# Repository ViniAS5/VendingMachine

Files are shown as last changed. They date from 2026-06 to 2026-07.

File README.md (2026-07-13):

# Máquina de Vendas - Integração FPGA e ESP32 (CYD)

Projeto de uma máquina de vendas automatizada para 3 tipos de refrigerantes em lata. O sistema demonstra a integração entre hardware dedicado e Internet das Coisas (IoT), utilizando uma FPGA para controle de precisão e um ESP32 como interface de usuário e servidor web local.

Projeto final desenvolvido para a disciplina de **Eletrônica Digital 2** (2026.1) do curso de **Engenharia Eletrônica** do **IFSC - Câmpus Florianópolis**.

## Hardware Utilizado
* **FPGA:** Terasic DE10-Lite (Controle lógico e acionamento PWM).
* **Microcontrolador:** ESP32 CYD - Cheap Yellow Display com tela touch de 2.8" (Interface Gráfica e Servidor Web).
* **Atuadores:** 3x Servo Motores (Para liberação física das latas).

## Arquitetura e Funcionamento

O fluxo de funcionamento do projeto une a interface física com uma simulação de pagamento via PIX:

1. **Acesso:** O ESP32 cria um ponto de acesso Wi-Fi local chamado "Máquina de Vendas".
2. **Interface Gráfica:** Pela tela touch do ESP32, o usuário seleciona o refrigerante desejado (Coca-Cola, Guaraná ou Sprite).
3. **Simulação de Pagamento:** Ao selecionar o produto, a tela exibe um QR Code. O usuário, conectado à rede Wi-Fi da máquina, escaneia o código com o celular e é direcionado para uma página web hospedada localmente no ESP32, que simula um aplicativo bancário.
4. **Comunicação 2 Fios:** Ao clicar em "PAGAR" no celular, o ESP32 envia um pulso de 300ms contendo um código binário de 2 bits para a FPGA.
5. **Acionamento:** A FPGA recebe o comando, realiza a estabilização do sinal (debounce) e altera o PWM da saída correspondente.
    * O sinal PWM opera em 50Hz (período de 20ms).
    * O ciclo do motor intercala larguras de pulso de **1.5ms** (repouso no centro), **0.8ms** (giro para soltar a lata) e **2.5ms** (retorno para engatilhar o próximo produto).

## Pinagem e Conexões

A comunicação entre o ESP32 e a FPGA é feita por um protocolo paralelo de 2 fios para enviar os comandos binários. 

**Atenção:** É obrigatório que os pinos **GND** do ESP32, da FPGA e da fonte de alimentação dos servo motores estejam **interconectados** para garantir a mesma referência de tensão.

| Componente de Origem | Pino / Porta | Destino | Função |
| :--- | :--- | :--- | :--- |
| **ESP32 (CYD)** | Pino 27 | FPGA (IO4) | Envio do Bit mais significativo (MSB) |
| **ESP32 (CYD)** | Pino 22 | FPGA (IO3) | Envio do Bit menos significativo (LSB) |
| **FPGA** | IO6 | Servo 1 | Sinal PWM - Libera Coca-Cola |
| **FPGA** | IO5 | Servo 2 | Sinal PWM - Libera Guaraná |
| **FPGA** | IO9 | Servo 3 | Sinal PWM - Libera Sprite |

## Desenvolvedores
* **Vinícius Abreu**
* **Breno Porcíncula**

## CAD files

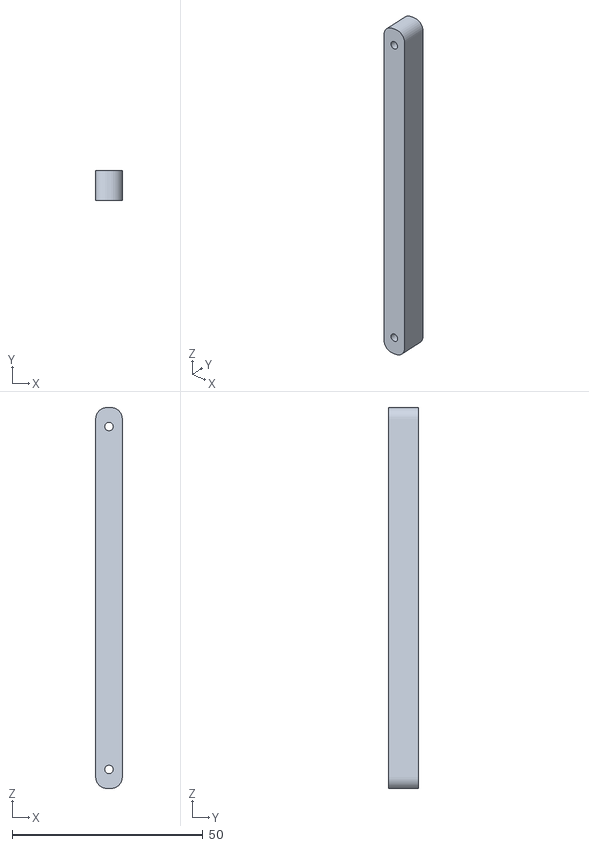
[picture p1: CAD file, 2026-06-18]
STL/HasteDispenser.stl
7.00 x 8.00 x 100.0

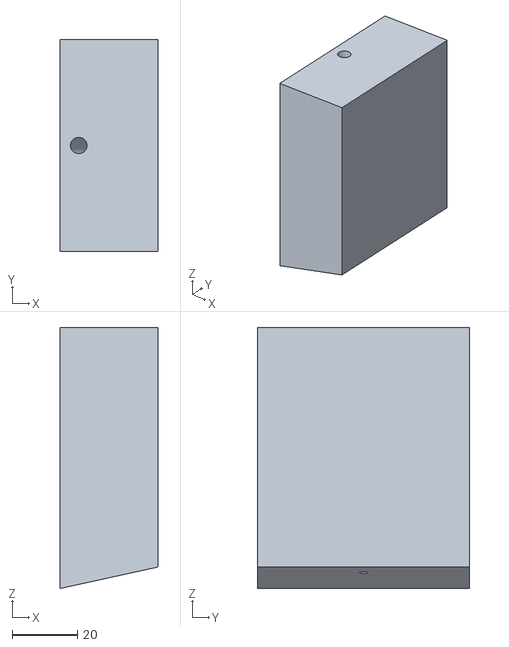
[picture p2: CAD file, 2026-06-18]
STL/ApoioDIspenser1.stl
30.0 x 65.0 x 80.0

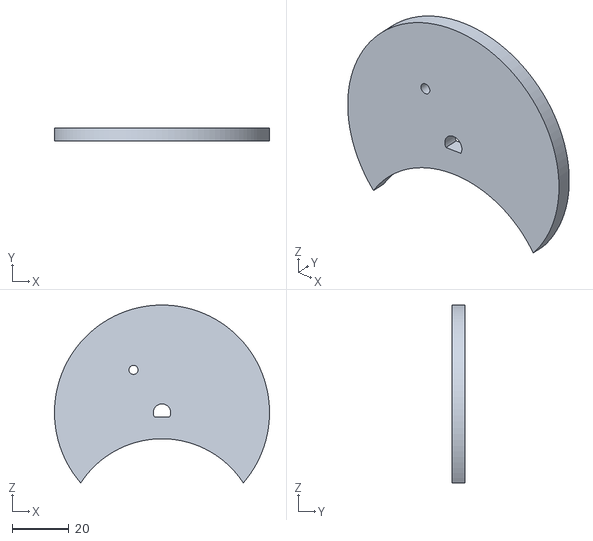
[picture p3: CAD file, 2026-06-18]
STL/TravaLata.stl
75.5 x 4.70 x 62.5

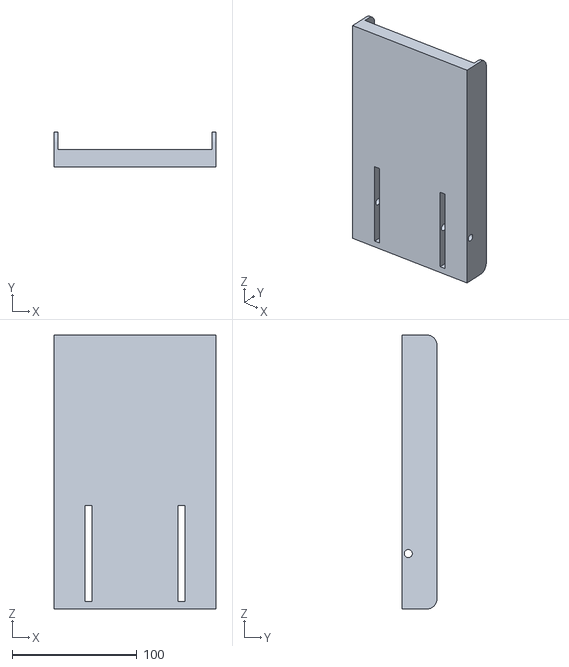
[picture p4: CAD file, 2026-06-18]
STL/Basedispenser.stl
130.0 x 28.0 x 220.0

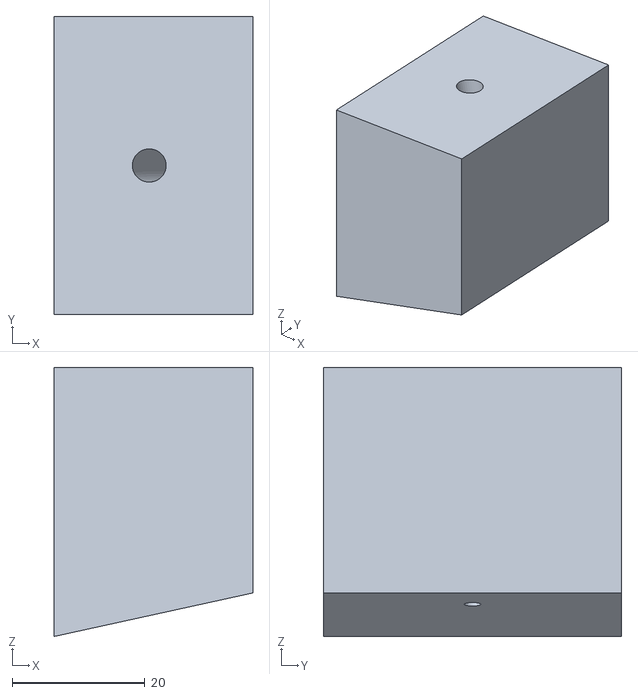
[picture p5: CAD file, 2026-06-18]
STL/ApoioDisopenser2.stl
30.0 x 45.0 x 40.6

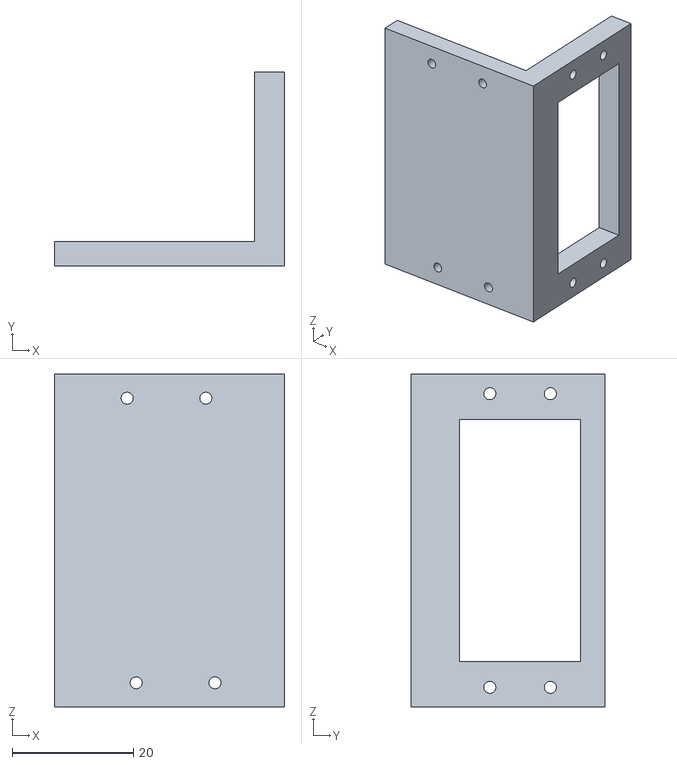
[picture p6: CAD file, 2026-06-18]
STL/SuporteServo.stl
38.0 x 32.0 x 55.0

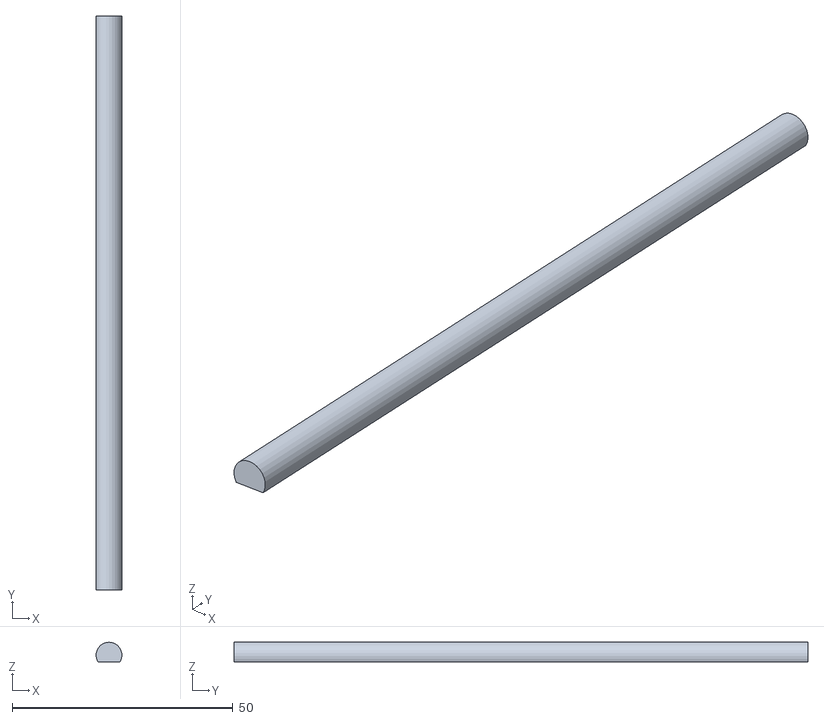
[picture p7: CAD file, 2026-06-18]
STL/EixoDispenser.stl
5.85 x 130.0 x 4.43

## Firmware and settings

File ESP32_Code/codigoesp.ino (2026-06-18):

/*
 * PROJETO MAQUINA DE VENDAS
 * O ESP32 cria uma rede WiFi, hospeda a pagina de pagamento e aciona a FPGA. 
 * Por: Vinícius Abreu e Breno Porcíncula
 */

#include <SPI.h>
#include <FS.h>
using namespace fs;
#include <TFT_eSPI.h> 
#include <XPT2046_Touchscreen.h>
#include <WiFi.h>
#include <WebServer.h>
#include <qrcoderm.h>

TFT_eSPI tft = TFT_eSPI();

const char* ssid = "Maquina de Vendas";
const char* password = "";
WebServer server(80);

#define PINO_BIT_0 22
#define PINO_BIT_1 27

#define XPT2046_IRQ 36
#define XPT2046_MOSI 32
#define XPT2046_MISO 39
#define XPT2046_CLK 25
#define XPT2046_CS 33

SPIClass touchSpi = SPIClass(2);
XPT2046_Touchscreen ts(XPT2046_CS, XPT2046_IRQ);

#define COR_FUNDO TFT_BLACK

struct Botao {
  int x, y, w, h;
  uint16_t corFundo, corTexto;
  String txt;
  byte codigoFPGA; 
};

Botao botoes[3] = {
  {10, 50,  300, 50, TFT_RED, TFT_BLACK, "Coca-Cola", 1},
  {10, 110, 300, 50, tft.color565(0, 180, 0), TFT_WHITE, "Guarana", 2},
  {10, 170, 300, 50, TFT_WHITE, tft.color565(0, 120, 0), "Sprite", 3}
};

bool aguardandoPagamento = false;
bool pagamentoRealizado = false;
Botao produtoPendente;

void handleRoot() {
  if (aguardandoPagamento) {
    String html = "<!DOCTYPE html><html><head><meta charset='UTF-8'><meta name='viewport' content='width=device-width, initial-scale=1'>";
    html += "<style>body{font-family: Arial, sans-serif; text-align: center; background-color: #f4f4f9; padding: 30px 20px;}";
    html += "h1{color: #333;} .box{background: white; padding: 20px; border-radius: 15px; box-shadow: 0px 4px 10px rgba(0,0,0,0.1); display: inline-block; width: 90%; max-width: 400px;}";
    html += "button{background-color: #32CD32; color: white; border: none; padding: 15px; font-size: 18px; font-weight: bold; border-radius: 10px; cursor: pointer; width: 100%; margin-top: 20px;}";
    html += "button:active{background-color: #28a428;} .footer{margin-top: 40px; font-size: 14px; color: #777;}</style></head><body>";
    
    // Logo do IFSC
    html += "<svg viewBox='0 0 66 90' width='55' height='75' xmlns='http://www.w3.org/2000/svg' style='margin-bottom:15px;'><g fill='#2f9e41'><rect x='0' y='24' width='18' height='18' rx='2'/><rect x='0' y='48' width='18' height='18' rx='2'/><rect x='0' y='72' width='18' height='18' rx='2'/><rect x='24' y='0' width='18' height='18' rx='2'/><rect x='24' y='24' width='18' height='18' rx='2'/><rect x='24' y='48' width='18' height='18' rx='2'/><rect x='24' y='72' width='18' height='18' rx='2'/><rect x='48' y='0' width='18' height='18' rx='2'/><rect x='48' y='48' width='18' height='18' rx='2'/></g><circle cx='9' cy='9' r='9' fill='#cd191e'/></svg>";
    
    html += "<div class='box'><h1>Simulador PIX</h1><p>Você está comprando:</p><h2 style='color:#cd191e;'>" + produtoPendente.txt + "</h2>";
    html += "<form action='/pagar' method='POST'><button type='submit'>SIMULAR PAGAMENTO</button></form></div>";
    
    html += "<div class='footer'>Por: Vinícius Abreu e Breno Porcíncula<br>Eletrônica Digital 2 2026.1</div>";
    
    html += "</body></html>";
    server.send(200, "text/html", html);
  } else {
    String html = "<!DOCTYPE html><html><head><meta charset='UTF-8'><meta name='viewport' content='width=device-width, initial-scale=1'></head>";
    html += "<body style='text-align:center; font-family:Arial; padding: 30px 20px; background-color: #f4f4f9;'>";
    
    html += "<svg viewBox='0 0 66 90' width='55' height='75' xmlns='http://www.w3.org/2000/svg' style='margin-bottom:15px;'><g fill='#2f9e41'><rect x='0' y='24' width='18' height='18' rx='2'/><rect x='0' y='48' width='18' height='18' rx='2'/><rect x='0' y='72' width='18' height='18' rx='2'/><rect x='24' y='0' width='18' height='18' rx='2'/><rect x='24' y='24' width='18' height='18' rx='2'/><rect x='24' y='48' width='18' height='18' rx='2'/><rect x='24' y='72' width='18' height='18' rx='2'/><rect x='48' y='0' width='18' height='18' rx='2'/><rect x='48' y='48' width='18' height='18' rx='2'/></g><circle cx='9' cy='9' r='9' fill='#cd191e'/></svg>";
    
    html += "<h2 style='color: #333; margin-top: 20px; max-width: 400px; display: inline-block; line-height: 1.4;'>Escolha um produto na tela da máquina para começar</h2>";
    
    html += "<div style='margin-top:40px; font-size:14px; color:#777;'>Por: Vinícius Abreu e Breno Porcíncula<br>Eletrônica Digital 2 2026.1</div>";
    
    html += "</body></html>";
    server.send(200, "text/html", html);
  }
}
void handlePagar() {
  pagamentoRealizado = true; 
  String html = "<!DOCTYPE html><html><head><meta charset='UTF-8'><meta name='viewport' content='width=device-width, initial-scale=1'>";
  html += "<style>body{font-family: Arial, sans-serif; text-align: center; background-color: #f4f4f9; padding: 30px 20px;}";
  html += ".box{background: white; padding: 30px; border-radius: 15px; box-shadow: 0px 4px 10px rgba(0,0,0,0.1); display: inline-block; border-top: 10px solid #32CD32;}";
  html += ".footer{margin-top: 40px; font-size: 14px; color: #777;}</style></head><body>";
  
  html += "<svg viewBox='0 0 66 90' width='55' height='75' xmlns='http://www.w3.org/2000/svg' style='margin-bottom:15px;'><g fill='#2f9e41'><rect x='0' y='24' width='18' height='18' rx='2'/><rect x='0' y='48' width='18' height='18' rx='2'/><rect x='0' y='72' width='18' height='18' rx='2'/><rect x='24' y='0' width='18' height='18' rx='2'/><rect x='24' y='24' width='18' height='18' rx='2'/><rect x='24' y='48' width='18' height='18' rx='2'/><rect x='24' y='72' width='18' height='18' rx='2'/><rect x='48' y='0' width='18' height='18' rx='2'/><rect x='48' y='48' width='18' height='18' rx='2'/></g><circle cx='9' cy='9' r='9' fill='#cd191e'/></svg>";
  
  html += "<div class='box'><h1 style='color: #32CD32;'>Pagamento Aprovado!</h1><p>O seu produto já está sendo liberado.</p></div>";
  
  html += "<div class='footer'>Por: Vinícius Abreu e Breno Porcíncula<br>Eletrônica Digital 2 2026.1</div>";
  
  html += "</body></html>";
  server.send(200, "text/html", html);
}

void desenharMenu();
void gerarTelaQRCode(Botao b);
void executarLiberacao(Botao b);

void setup() {
  Serial.begin(115200);
  
  pinMode(PINO_BIT_0, OUTPUT); 
  pinMode(PINO_BIT_1, OUTPUT); 
  digitalWrite(PINO_BIT_0, LOW);
  digitalWrite(PINO_BIT_1, LOW);

  tft.init(); tft.setRotation(1); tft.invertDisplay(false); 
  touchSpi.begin(XPT2046_CLK, XPT2046_MISO, XPT2046_MOSI, XPT2046_CS);
  ts.begin(touchSpi); ts.setRotation(1); 

  tft.fillScreen(COR_FUNDO);
  tft.setTextColor(TFT_WHITE); tft.setTextSize(2); tft.setTextDatum(MC_DATUM);
  tft.drawString("Iniciando Roteador...", 160, 120);
  
  WiFi.softAP(ssid, password);
  
  server.on("/", HTTP_GET, handleRoot);
  server.on("/pagar", HTTP_POST, handlePagar);
  server.begin();

  delay(1000);
  desenharMenu();
}

void loop() {
  server.handleClient();

  if (pagamentoRealizado && aguardandoPagamento) {
    executarLiberacao(produtoPendente);
    pagamentoRealizado = false;
    aguardandoPagamento = false;
  }

  if (ts.touched()) {
    TS_Point p = ts.getPoint();
    int t_x = map(p.x, 200, 3700, 0, 320);
    int t_y = map(p.y, 240, 3800, 0, 240);

    if (aguardandoPagamento) {
      aguardandoPagamento = false;
      pagamentoRealizado = false;
      desenharMenu();
      while(ts.touched()) { delay(10); } 
      return;
    }

    for (int i = 0; i < 3; i++) {
      if (t_x > botoes[i].x && t_x < (botoes[i].x + botoes[i].w) &&
          t_y > botoes[i].y && t_y < (botoes[i].y + botoes[i].h)) {
        produtoPendente = botoes[i];
        aguardandoPagamento = true;
        pagamentoRealizado = false;
        gerarTelaQRCode(produtoPendente);
        while(ts.touched()) { delay(10); } 
        break; 
      }
    }
  }
}

void executarLiberacao(Botao b) {
  tft.fillScreen(COR_FUNDO); 
  
  tft.setTextColor(TFT_GREEN); tft.setTextSize(3); tft.setTextDatum(MC_DATUM);
  tft.drawString("PAGAMENTO ACEITO!", 160, 80);
  
  tft.setTextColor(TFT_WHITE); 
  tft.drawString("Liberando:", 160, 130);
  tft.drawString(b.txt, 160, 170); 
  
  // Envio dos dados para a FPGA
  digitalWrite(PINO_BIT_0, bitRead(b.codigoFPGA, 0)); 
  digitalWrite(PINO_BIT_1, bitRead(b.codigoFPGA, 1)); 
  delay(300); 
  
  digitalWrite(PINO_BIT_0, LOW); 
  digitalWrite(PINO_BIT_1, LOW); 
  delay(2500); 
  desenharMenu(); 
}

void gerarTelaQRCode(Botao b) {
  tft.fillScreen(TFT_WHITE); 
  tft.setTextColor(TFT_BLACK); 
  tft.setTextSize(2); 
  tft.setTextDatum(TC_DATUM);
  tft.drawString("Pague com PIX:", 160, 10);
  tft.drawString(b.txt, 160, 35);
  tft.setTextSize(1); 
  tft.drawString("Conecte no WiFi 'Maquina de Vendas'", 160, 210);
  tft.drawString("(Toque na tela para cancelar)", 160, 225);

  String urlCompleta = "http://192.168.4.1/";
  
  QRCode qrcode;
  uint8_t qrcodeData[qrcode_getBufferSize(3)];
  qrcode_initText(&qrcode, qrcodeData, 3, ECC_LOW, urlCompleta.c_str());

  int mult = 4; 
  int offX = (320 - (qrcode.size * mult)) / 2;
  int offY = (240 - (qrcode.size * mult)) / 2 + 10;

  for (uint8_t y = 0; y < qrcode.size; y++) {
    for (uint8_t x = 0; x < qrcode.size; x++) {
      if (qrcode_getModule(&qrcode, x, y)) {
        tft.fillRect(offX + (x * mult), offY + (y * mult), mult, mult, TFT_BLACK);
      }
    }
  }
}

void desenharMenu() {
  tft.fillScreen(COR_FUNDO); 
  tft.setTextColor(TFT_YELLOW); tft.setTextSize(2); tft.setTextDatum(TC_DATUM); 
  tft.drawString("SELECIONE O PRODUTO", 160, 10);
  for (int i = 0; i < 3; i++) {
    tft.fillRoundRect(botoes[i].x, botoes[i].y, botoes[i].w, botoes[i].h, 10, botoes[i].corFundo); 
    tft.drawRoundRect(botoes[i].x, botoes[i].y, botoes[i].w, botoes[i].h, 10, TFT_WHITE); 
    tft.setTextColor(botoes[i].corTexto); tft.setTextDatum(MC_DATUM); 
    tft.drawString(botoes[i].txt, botoes[i].x + (botoes[i].w / 2), botoes[i].y + (botoes[i].h / 2));
  }
}

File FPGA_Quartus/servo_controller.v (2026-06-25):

module servo_controller (
    input  wire clk_50mhz,    // Clock de 50 MHz
    input  wire [1:0] cmd_in, // Entrada de 2 Fios do ESP32
    output wire pwm1,         // Saída 1 (Coca)
    output wire pwm2,         // Saída 2 (Guarana)
    output wire pwm3          // Saída 3 (Sprite)
);
    // Constantes pra tempo e frequencia
    parameter PWM_PERIOD  = 1000000;
    parameter PULSE_1_5MS = 75000;
    parameter PULSE_0_8MS = 40000;
    parameter PULSE_2_5MS = 125000;
    parameter TIME_1_SEC  = 50000000;
    parameter TIME_2_SEC  = 100000000;
    
    // Tempo de espera de 10 milissegundos (500.000 pulsos)
    parameter TIME_SETTLE = 500000; 

    // Tempo da trava de inicialização: 3 segundos (150.000.000 pulsos)
    parameter TIME_BOOT_DELAY = 150000000;

    // Registradores
    reg [19:0] pwm_counter = 0;
    reg [26:0] routine_timer = 0;
    reg [19:0] active_pulse = PULSE_1_5MS; 
    reg is_running = 0;
    reg [1:0] latched_cmd = 0; 

    // Registradores pra delay
    reg waiting_cmd = 0;
    reg [19:0] settle_timer = 0;
    
    // Registradores para a Trava de Boot
    reg [27:0] boot_timer = 0;
    reg boot_done = 0;

    // Gerador da freq do pwm (50Hz)
    always @(posedge clk_50mhz) begin
        if (pwm_counter >= PWM_PERIOD - 1) begin
            pwm_counter <= 0;
        end else begin
            pwm_counter <= pwm_counter + 1;
        end
    end

    // Controlador da sequência de movimentos
    always @(posedge clk_50mhz) begin
        
        // Logica da trava enquanto o esp inicia
        if (!boot_done) begin
            // Força a máquina a ficar parada no meio e limpa os comandos
            active_pulse <= PULSE_1_5MS;
            latched_cmd <= 2'b00;
            is_running <= 0;
            waiting_cmd <= 0;
            
            // Conta até 3 segundos
            boot_timer <= boot_timer + 1;
            if (boot_timer >= TIME_BOOT_DELAY) begin
                boot_done <= 1; // Libera o funcionamento da máquina
            end
        end 
        
        // Voltando a operar normalmente
        else begin
            // Pra estabilizar o sinal
            if (cmd_in != 2'b00 && !is_running && !waiting_cmd) begin
                waiting_cmd <= 1;   // Inicia a contagem de espera
                settle_timer <= 0;
            end

            // Timer antes de ler o esp
            if (waiting_cmd) begin
                settle_timer <= settle_timer + 1;
                if (settle_timer > TIME_SETTLE) begin
                    is_running <= 1;
                    routine_timer <= 0;
                    latched_cmd <= cmd_in; 
                    waiting_cmd <= 0;
                end
            end

            // Rotina dos motores
            if (is_running) begin
                routine_timer <= routine_timer + 1;
                
                if (routine_timer < TIME_1_SEC) begin
                    active_pulse <= PULSE_0_8MS;  // solta latinha
                end 
                else if (routine_timer < TIME_2_SEC) begin
                    active_pulse <= PULSE_2_5MS;  // pega latinha
                end 
                else begin
                    is_running <= 0;
                    routine_timer <= 0;
                    active_pulse <= PULSE_1_5MS;  // volta pro meio
                    latched_cmd <= 2'b00;         // limpa a memória
                end
            end else if (!waiting_cmd) begin
                active_pulse <= PULSE_1_5MS;      // fica no meio
            end
        end
    end

    // Demux pras saidas
    wire sig_routine = (pwm_counter < active_pulse); 
    wire sig_center  = (pwm_counter < PULSE_1_5MS);  

    // Roteamento
    assign pwm1 = (latched_cmd == 2'b01) ? sig_routine : sig_center;
    assign pwm2 = (latched_cmd == 2'b10) ? sig_routine : sig_center;
    assign pwm3 = (latched_cmd == 2'b11) ? sig_routine : sig_center;

endmodule
